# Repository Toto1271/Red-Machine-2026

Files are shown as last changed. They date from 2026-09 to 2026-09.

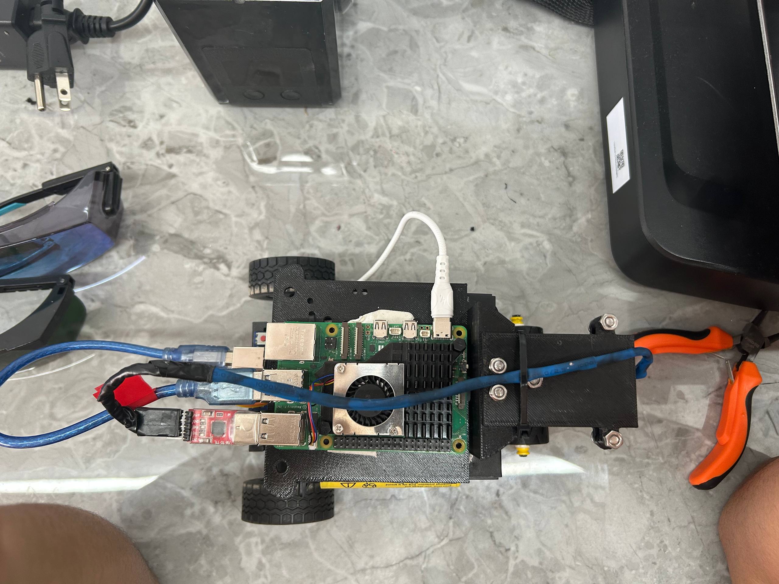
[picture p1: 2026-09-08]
v-photos/photo_4920741823874010308_w.jpg

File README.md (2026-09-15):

# Documento de Ingeniería / Red Machine

Este repositorio muestra todos los componentes para construir a "pompo", este robot autonomo pertenece al equipo "Red Machine" y cumple el proposito de participar en la categoria de futuros ingenieros en la WRO 2026.



# INDICE - REDMACHINE 2026

En este repositorio se puede observar la evolucion del equipo Red Machine asi como su trabajo durante mas de 3 años en la WRO. A través de diversos commits se pueden visualizar los avances que se han tenido durante esta temporada 2026 en procesos de ingeniería, tanto físicos como de computacion y programacion. 
Aquí se podrá observar las decisiones que se han tomado y el por que, y todas las mejoras que se han tomado para llegar a la ultima version hasta el momento que se tiene del robot. 

## 📌 CONTENIDO PRINCIPAL

1. [Documento de Ingeniería / Red Machine](#documento-de-ingeniería--red-machine)
2. [Introducción](#introduccion)
3. [Miembros de Red Machine](#miembros-de-red-machine)
   - [Juan Diego Cano Barros](#-juan-diego-cano-barros)
   - [Samuel José Galban Franco](#-samuel-josé-galban-franco)
   - [Angel Saúl Rodríguez Guerra](#-angel-saúl-rodriguez-guerra)
4. [Fotos del Robot (Todos los Ángulos)](#fotos-desde-todos-los-angulos)
5. [Diseño y Fabricación Mecánica](#-diseño-y-fabricación-mecánica)
   - [Fabricación Digital y Selección de Materiales](#1-fabricación-digital-y-selección-de-materiales)
   - [Análisis del Chasis Inferior (Placa Base)](#2-análisis-detallado-del-chasis-inferior-placa-base)
   - [Análisis del Segundo Piso y Unión entre Niveles](#3-análisis-detallado-del-segundo-piso-y-unión-entre-niveles)
   - [Módulo de Ruedas y Selección de Neumáticos](#4-módulo-de-ruedas-y-selección-de-neumáticos)
   - [Evolución del Chasis y Prototipado CAD](#5-evolución-del-chasis-y-prototipado-cad)
   - [Módulo de Tracción y Centro de Masa](#6-módulo-de-tracción-y-centro-de-masa)
   - [Módulo de Dirección y Comportamiento Dinámico](#7-módulo-de-dirección-y-comportamiento-dinámico)
   - [Integración de Sensores y Estructura Superior](#8-integración-de-sensores-y-estructura-superior)
6. [Explicación Detallada de los Componentes Electrónicos](#explicación-detallada-de-los-componentes)
   - [Raspberry Pi 5](#raspberry-pi-5)
   - [Arduino Uno](#arduino-uno)
   - [Lidar LDROBOT ST27L](#lidar-ldrobot-st27l)
   - [Servomotor REV Robotics](#servomotor-rev-robotics)
   - [Driver TB6612FNG (Puente H Dual)](#driver-tb6612fng-puente-h-dual)
   - [Cámara Webcam](#cámara-webcam)
   - [Banco de Baterías 18650 (2S2P)](#banco-de-baterías-18650-arreglo-2s2p)
   - [Reductor de Voltaje XL4015](#reductor-de-voltaje-xl4015-step-down-5-a)
   - [Reductor de Voltaje LM2596](#reductor-de-voltaje-lm2596-step-down-3-a)
7. [Alimentación del Robot](#alimentación-del-robot)
   - [Cálculo del Consumo Total de Energía](#-cálculo-del-consumo-total-de-energía)
   - [Distribución de Potencia y Autonomía Estimada](#-distribución-de-potencia-y-autonomía-estimada)
8. [Buenas Prácticas de Cableado, Eficiencia y Seguridad](#buenas-prácticas-de-cableado-eficiencia-y-seguridad)
9. [Arquitectura Funcional y Distribución Eléctrica](#arquitectura-funcional-y-distribución-eléctrica)
   - [Capa de Distribución Energética (Power Layer)](#1-capa-de-distribución-energética-power-layer)
   - [Nivel de Procesamiento Jerárquico (Compute Layer)](#2-nivel-de-procesamiento-jerárquico-compute-layer)
   - [Etapa de Tracción y Movilidad (Motor Control Layer)](#3-etapa-de-tracción-y-movilidad-motor-control-layer)
   - [Subsistema de Percepción del Entorno (Sensor Layer)](#4-subsistema-de-percepción-del-entorno-sensor-layer)
   - [Diagrama de Flujo Eléctrico (Mermaid)](#a-continuacion-un-diagrama-que-demuestra-de-manera-mas-sencilla-la-forma-en-la-que-se-alimenta-el-robot)
10. [Preparación de la Raspberry Pi (Software)](#preparación-de-la-raspberry-pi)
    - [Descarga e instalación de Ubuntu Server](#descarga-e-instalación-de-ubuntu-server-en-la-microsd)
    - [Primer arranque y configuración inicial](#primer-arranque-y-configuración-inicial)
    - [Configuración de la red (Wi-Fi e IP fija)](#configuración-de-la-red-wi-fi-e-ip-fija)
11. [Instalación de ROS 2 Jazzy](#instalación-de-ros-2-jazzy-en-la-raspberry-pi)
    - [Configuración del locale](#configuración-del-locale)
    - [Adición del repositorio de ROS 2](#adición-del-repositorio-de-ros-2)
    - [Instalación de ROS 2 Jazzy](#instalación-de-ros-2-jazzy-en-la-raspberry-pi-1)
    - [Configuración del entorno](#configuración-del-entorno)
12. [Configuración del entorno de desarrollo (VS Code Remote)](#configuración-del-entorno-de-desarrollo-en-tu-ordenador-local)
    - [Instalación de Visual Studio Code](#instalación-de-visual-studio-code)
    - [Instalación de la extensión Remote-SSH](#instalación-de-la-extensión-remotessh)
    - [Conexión remota a la Raspberry Pi](#conexión-remota-a-la-raspberry-pi-desde-vs-code)
13. [Preparación del código en la Raspberry Pi](#preparación-del-código-en-la-raspberry-pi)
    - [Creación del workspace de ROS 2](#creación-del-workspace-de-ros-2)
    - [Creación del paquete y del nodo](#creación-del-paquete-y-del-nodo)
    - [Instalación de dependencias Python](#instalación-de-dependencias-python)
14. [Configuración del Arduino Uno](#configuración-del-arduino-uno)
    - [Instalación del Arduino IDE](#instalación-del-arduino-ide-en-ubuntu)
    - [Configuración de permisos del puerto serial](#configuración-de-permisos-del-puerto-serial)
    - [Conexión física del Arduino Uno](#conexión-física-del-arduino-uno-a-la-raspberry-pi)
    - [Compilación y carga del código](#compilación-y-carga-del-código-en-el-arduino)
15. [Comunicación Serial entre ROS 2 y Arduino](#comunicación-serial-entre-ros-2-y-arduino)
    - [Identificación del puerto serial](#identificación-del-puerto-serial)
    - [Permisos del puerto serial](#permisos-del-puerto-serial)
    - [Creación de una regla udev permanente](#creación-de-una-regla-udev-permanente)
16. [Compilación y ejecución del proyecto](#compilación-y-ejecución-del-proyecto)
    - [Compilación del workspace](#compilación-del-workspace)
    - [Configuración de variables de entorno](#configuración-de-variables-de-entorno)
    - [Ejecución del nodo](#ejecución-del-nodo)
17. [Explicación Detallada del Código del Reto Abierto](#explicación-detallada-del-código-del-reto-abierto-y-su-lógica)
    - [Lógica de Navegación Global](#lógica-de-navegación-global)
    - [Nodo ROS 2 (Configuración Inicial, Callback, Filtrado)](#explicacion-codigo-reto-abierto-nodo-ros-2)
    - [Algoritmo de Seguimiento de Pared con SVD](#algoritmo-de-seguimiento-de-pared-con-svd-singular-value-decomposition)
    - [Comunicación con el Arduino](#comunicación-con-el-arduino)
18. [Análisis del Código Arduino (Controlador de Bajo Nivel)](#análisis-del-código-arduino-controlador-de-bajo-nivel)
    - [Control del Motor con PWM](#1-control-del-motor-con-pwm)
    - [Manejo de Comandos Seriales](#2-manejo-de-comandos-seriales)
19. [Solución de problemas comunes](#solución-de-problemas-comunes)
20. [Recomendaciones finales](#recomendaciones-finales)
21. [Videos del Robot](#videos)
    - [Video Actual Reto 1](#video-actual-reto-1)
    - [Video Actual Reto 2](#video-actual-reto-2)
    - [Videos del robot versión 1.0](#videos-del-robot-versión-10)
    - [Videos del robot versión 2.0](#videos-del-robot-versión-20)
    - [Demostraciones y pruebas](#videos-del-robot)
    - [Videos sobre Red Machine](#videos-sobre-red-machine)
22. [Historia y Cronología de Red Machine](#historia-y-cronología-de-red-machine)
    - [Temporada 2023](#temporada-2023)
    - [Temporada 2024](#temporada-2024)
    - [Temporada 2025](#temporada-2025)
23. [Evolución de los Robots (Julián, Luka y Pompo)](#julian-luka-and-pompo)
    - [JULIAN 1.0 a 5.0](#julian-10)
    - [LUKA 1.0 a 3.0](#luka-10)
    - [POMPO 1.0 a 3.0](#pompo-10)
24. [Decisiones de Ingeniería](#decisiones-de-ingeniería)
    - [Filosofía de Diseño y Estrategia](#1-filosofía-de-diseño-y-estrategia)
    - [Sistema de Alimentación y Tracción](#2-sistema-de-alimentación-y-tracción)
    - [Sistemas de Navegación y Sensores](#3-sistemas-de-navegación-y-sensores)
    - [Integración y Control](#4-integración-y-control)

# Contenido

Este repositorio contiene los siguientes directorios para organizar nuestro proyecto:

* `t-photos`: Incluye fotos del equipo, así como fotos del trabajo realizado durante todos los años de competencia y fotos de los robots construidos por el equipo.
* `v-photos`: Contiene 6 fotos del vehículo (desde todos los ángulos).
* `schemes`: Diagramas esquemáticos (JPEG, PNG o PDF) de los componentes electromecánicos, que ilustran el cableado de los elementos electrónicos y motores, además de una explicación de la función de cada uno.
* `src`: Código del software de control para todos los componentes programados para la competencia.
* `models`: Archivos para el diseño 3D del vehículo.
* `other`: Archivos adicionales para entender cómo preparar el vehículo para la competencia.
     
# Introduccion
El equipo ha puesto su mayor esfuerzo en construir el mejor robot posible. Nuestra preparación para estas olimpiadas se ha basado en un amplio aprendizaje en construcción, diseño y programación, y la experiencia de competencias anteriores ha sido fundamental. Largas horas de análisis de pistas y estudio han llevado a la creación de nuestra propia estrategia, basada en los componentes con los que el equipo decidió trabajar, apuntando al mejor rendimiento posible en las distintas etapas de esta competencia.
A lo largo de este documento y de todo el repositorio, se explica con precisión todo el trabajo de diseño, programación y construcción del robot.

# Miembros de Red Machine

## 👤 Juan Diego Cano Barros

### Rol en el equipo
Responsable de la programación del robot y de la electrónica del mismo.

### 🧠 Logros académicos

- 🥉 **Medalla de Bronce – Olimpiada Iberoamericana de Matemáticas (2023)**
Representó a Venezuela en la 29ª edición de esta competencia internacional organizada por la OMA en Argentina, tras ser seleccionado entre los 10 mejores del segundo nivel nacional por @acmvenojm.

- 🥈 **Subcampeón – Argentine Mathematics Olympiad Ñandú (2019)**
Participó en el examen oral en Buenos Aires, destacándose como subcampeón en el Nivel 1.

---

### Antecedentes en robótica

- 🇻🇪 **Tricampeón Nacional – Categoría Futuros Ingenieros (WRO Venezuela)**
Ganador de la Olimpiada Nacional de Robótica en tres ediciones consecutivas, representando al estado Zulia y clasificando a las finales internacionales.

- 🌍 **Finalista Internacional – WRO Panamá 2023**
Representó a Venezuela en la Olimpiada Mundial de Robótica, ubicándose en el puesto 25 de 40 equipos en la categoría Futuros Ingenieros.

- 🇹🇷 **Participación Internacional – WRO Turquía 2024**
Formó parte de la delegación venezolana que compitió en la edición mundial celebrada en Turquía, consolidando experiencia en eventos globales de alto nivel.

---

### 💡 Motivación y Enfoque
Comer, dormir, conocer gente, disfrutar de los viajes y dormir

## 👤 Samuel José Galban Franco

### Rol en el equipo
Responsable del repositorio del robot.

### 🧠 Logros académicos

- 🥈 **Subcampeón – Olimpiada Nacional de Química (2024)**
Representó al Liceo Los Robles dicha edición de esta competencia organizada por AVOQUIM.

- 🥈 **Subcampeón – DESAFÍO VIRTUAL MISSIONS PANAMÁ 2023**
Segundo lugar en esta competencia internacional, representando a Venezuela durante la final internacional de la WRO 2023 celebrada en Panamá.

- 🥈 **Medalla de plata – Olimpiada internacional de nanotecnología INOHS**
Participación destacada en la final internacional, formando parte de la delegación Venezolana el año 2025. 

---

### 🤖 Antecedentes en robótica

- 🇻🇪 **Tricampeón Nacional – Categoría Futuros Ingenieros (WRO Venezuela)**
Ganador de la Olimpiada Nacional de Robótica en tres ediciones consecutivas, representando al estado Zulia y clasificando a las finales internacionales.

- 🌍 **Finalista Internacional – WRO Panamá 2023**
Representó a Venezuela en la Olimpiada Mundial de Robótica, ubicándose en el puesto 25 de 40 equipos en la categoría Futuros Ingenieros.

- 🇹🇷 **Participación Internacional – WRO Turquía 2024**
Formó parte de la delegación venezolana que compitió en la edición mundial celebrada en Turquía, consolidando experiencia en eventos globales de alto nivel.

---

### 💡 Motivación y Enfoque
Conocer gente, disfrutar de los viajes y buscar oportunidades de estudio

## 👤 Angel Saúl Rodriguez Guerra

### Rol en el equipo
Responsable de la mecánica del robot

### 🧠 Logros académicos
- 🥇 **Clasificado para el Mundial – Olimpiada Mundial Juvenil de Matemáticas (WYMO) (2024)**
Representó a Venezuela en la Olimpiada Mundial Juvenil de Matemáticas, una competencia internacional que reúne a jóvenes talentos de las matemáticas de todo el mundo para enfrentarse a problemas de alto nivel de exigencia.

- 🔬 **Participante destacado – Olimpiadas de Química y Matemáticas en Venezuela**
Competido en varias ediciones de las Olimpiadas venezolanas, demostrando excelencia y pasión por las ciencias exactas desde una edad temprana.

--- 

### 🤖 Antecedentes en robótica

- 🇻🇪 **Tricampeón Nacional – Categoría Futuros Ingenieros (WRO Venezuela)**
Ganador de la Olimpiada Nacional de Robótica en tres ediciones consecutivas, representando al estado Zulia y clasificando a las finales internacionales.

- 🌍 **Finalista Internacional – WRO Panamá 2023**
Representó a Venezuela en la Olimpiada Mundial de Robótica, ubicándose en el puesto 25 de 40 equipos en la categoría Futuros Ingenieros.

- 🇹🇷 **Participación Internacional – WRO Turquía 2024**
Formó parte de la delegación venezolana que compitió en la edición mundial celebrada en Turquía, consolidando experiencia en eventos globales de alto nivel.

--- 

### 💡 Motivación y Enfoque
Apasionado por el aprendizaje continuo, la resolución creativa de problemas y la colaboración en equipos multidisciplinarios. Su trayectoria en competencias académicas y tecnológicas refleja una motivación genuina para generar un impacto a través del conocimiento y seguir explorando nuevas fronteras del pensamiento científico y la innovación.

---



# Fotos desde todos los angulos

## Montaje actual (WRO nacional) 
La construcción del robot se mantuvo en su mayor parte, manteniendo la posicion de los sistema de manteniniento, sensores y alimentacion, pudiendose observar dos cambios para el vehículo que competirá en la final nacional: 
   - **Cambio estructural:** En el robot se añade una nueva parte impresa en material 3D, que cumple la funcion de tener un mejor recubrimiento en la electronica. 
   - **Fijacion del boton de inicio:** En la nueva estructura impresa se colocó un pequeño espacio para poder fijar el botón de inicio, y mantenerlo estable a la hora de las practicas para impedir daños en dicho sistema. 

|  |  |  |
| :----: | :---: | :---: |
|  |  |  |

# ⚙️ Diseño y Fabricación Mecánica

## 1. Fabricación Digital y Selección de Materiales

* **Diseño CAD e Impresión 3D:** El vehículo fue modelado en software CAD (Autodesk Fusion 360 para volumetría 3D y AutoCAD para perfiles dimensionales de precisión). Toda la fabricación física se realizó en una impresora Creality K1 Max, lo que permitió iterar el chasis con soltura y ajustar tolerancias sobre la marcha.
* **Elección del PETG frente a otros materiales:**
  * **PLA:** Excesivamente rígido y frágil; propenso a fracturas ante impactos o vibraciones.
  * **ABS / ASA:** Propenso a contracción al enfriarse (*warping*), deformando piezas planas del chasis.
  * **Nylon (PA):** Alta higroscopía y mayor complejidad de procesamiento sin ventajas críticas inmediatas.
  * **PETG (Seleccionado):** Equilibrio perfecto entre tenacidad a impactos, flexibilidad justa, estabilidad dimensional y facilidad de procesamiento.
* **Parámetros de Impresión Predeterminados (Creality Print):**
  * **Temperatura de Boquilla:** 240 °C - 245 °C
  * **Temperatura de la Cama:** 70 °C - 80 °C
  * **Velocidad de Impresión:** 50 mm/s - 100 mm/s
  * **Relleno (Infill) y Patrón:** 15% - 20% (Grid / Gyroid)
  * **Enfriamiento de Capa:** 30% - 50%

---

## 2. Análisis Detallado del Chasis Inferior (Placa Base)

)

* **Módulo Frontal de Dirección (Cuello y Alojamiento Servo):**
  * **Hueco Rectangular Central:** Diseñado a medida para embutir el servomotor de dirección a presión, evitando desplazamientos horizontales al aplicar torque.
  * **Orificios Pasantes M5:** Patrón de cuatro perforaciones perimetrales calibradas para tornillos M5 que fijan el subchasis superior de la dirección.
* **Módulo Trasero de Tracción (Caja, Motores y Salida de Ruedas):**
  * **Cavidades Longitudinales Dobles:** Espacios calados a medida para albergar dos motores eléctricos DC y definir la trocha trasera.
  * **Pieza de Acoplamiento Inter-Motor:** Canal central con puente rígido impreso que conecta ambos motores entre sí, eliminando torsiones independientes al acelerar.
  * **Aberturas Laterales Posteriores:** Muescas/huecos calados en los bordes laterales del chasis cerca del extremo trasero, diseñados específicamente para permitir el paso y salida de los ejes y neumáticos de tracción sin roces con la estructura.
* **Puntos de Fijación Posteriores:**
  * **Pestañas Traseras Perforadas:** Dos extensiones finales que sirven como puntos de anclaje traseros para la estructura del nivel superior.

---

## 3. Análisis Detallado del Segundo Piso y Unión entre Niveles

)

* **Unión Física entre el Primer y Segundo Piso:**
  * **Portabaterías como Columnas de Apoyo:** Los portabaterías dobles para celdas Li-Ion 18650 están colocados en los laterales entre ambas placas, funcionando como las paredes/columnas de soporte principales que elevan la estructura y bajan el centro de gravedad.
  * **Fijación Frontal con Dos Tornillos:** Dos tornillos pasantes atornillan la parte delantera del segundo piso al chasis inferior para eliminar vibraciones en la zona del sensor.
* **Componentes en la Cara Superior del Segundo Piso:**
  * **Raspberry Pi 5:** Montada en la zona central sobre cuatro orificios M3 con *standoffs* mecánicos para ventilación y aislamiento de vibraciones.
  * **Sensor LiDAR:** Instalado en la pestaña frontal elevada (~10 cm del suelo) para escanear la pista por encima de las paredes sin obstáculos ni puntos ciegos.
* **Componentes en la Cara Inferior del Segundo Piso (Montaje de Cabeza):**
  * **Ubicación Invertida:** El driver de potencia (Puente H) y los dos reductores de voltaje (Buck Converters) van suspendidos boca abajo en la cara inferior, orientados hacia el primer piso para ahorrar espacio superior.
  * **Sujeción por Remaches y Alambres:** Fijados combinando remaches rígidos contra vibraciones y alambres de amarre técnico que funcionan como abrazaderas sin ocupar volumen adicional con tuercas o tornillos.
  * **Alimentación Separada:** Reductores independientes para aislar la línea del procesador de la línea de potencia de los motores.

---

## 4. Módulo de Ruedas y Selección de Neumáticos

)

La selección de neumáticos se abordó separando técnicamente las funciones de **tracción** y **dirección**, ya que cada una exige propiedades físicas distintas: la tracción necesita maximizar agarre y transferencia de torque, mientras que la dirección necesita minimizar resistencia e inercia al giro. Por eso se optó por un principio de selección combinada, usando dos tipos de rueda Lego Technic distintos según la función de cada eje, en lugar de un único modelo para las cuatro ruedas.

### Tren Trasero (Tracción)

Se utilizaron ruedas Lego Technic medianas de banda ancha (49.5 x 20 mm). Su banda de rodadura ancha y su compuesto de goma suave maximizan la superficie de contacto con la pista, lo que evita el patinaje al acelerar a fondo con los motores DC y asegura una transferencia de torque eficiente. El diámetro se eligió específicamente para equilibrar torque y velocidad lineal, evitando sobrecargar la etapa de potencia del sistema.

Esta elección también resultó relevante para la estabilidad general del robot: durante las primeras pruebas de rodaje se detectaron derrapes frecuentes, corregidos finalmente invirtiendo la orientación de los motores traseros (ver Sección 5.1). Una banda de rodadura de menor agarre en este punto habría dificultado aún más esa corrección.

### Tren Delantero (Dirección)

Para el eje delantero se emplearon ruedas Lego Technic pequeñas de bajo perfil, montadas sobre manguetas articuladas Lego Technic. Su diámetro reducido y huella angosta minimizan el momento de inercia y la resistencia a la rotación lateral, permitiendo virajes inmediatos sin forzar ni sobrecalentar el servomotor de dirección.

Además, se definió una trocha delantera más estrecha que la trasera, buscando específicamente evitar el sobreviraje (*drifting*) y lograr curvas más fluidas y predecibles. El perfil bajo de esta rueda también fue una decisión deliberada de espacio: evita interferencias mecánicas con el sensor LiDAR, montado justo por encima de este eje.

---

## 5. Evolución del Chasis y Prototipado CAD

El desarrollo del chasis no partió de un diseño final, sino de un proceso iterativo de prueba y corrección: cada versión se construyó para resolver un problema concreto detectado en la anterior. A continuación se documenta esa evolución.

### 5.1. Piso Inferior (Chasis Base)

**Prototipo 1 — Silueta monocapa (boceto de referencia)**

El primer prototipo fue una placa plana simple, sin ningún detalle funcional. Su objetivo no era ser una pieza definitiva, sino tener por primera vez una base física del robot que permitiera observar el avance real de la estructura y, sobre todo, medir con precisión dónde debían ubicarse los sensores, las tarjetas electrónicas y los motores dentro del chasis. Como era de esperarse, esta primera versión no era funcional: le faltaban todos los detalles específicos (cajas, huecos, anclajes) necesarios para encajar los componentes del robot.

)

**Prototipo 2 — Caja inferior integrada**

A partir de las medidas obtenidas en el Prototipo 1, se integró una caja diseñada a medida donde los motores encajan por presión, evitando así depender de tornillos u otro método de fijación adicional para sujetarlos. Este acople resultó tan preciso que se mantiene sin cambios hasta el diseño final. De igual forma, el hueco para el servomotor de dirección quedó correctamente dimensionado desde esta iteración y tampoco requirió modificaciones posteriores.

)

**Prototipo 3 — Nivelación de tracción y liberación de espacio para el LiDAR**

Con la caja de motores ya resuelta, surgió un nuevo problema: las ruedas de tracción trasera y las ruedas de dirección delantera no quedaban al mismo nivel. Para corregirlo, se profundizó la caja inferior hasta emparejar ambos ejes. Además, se eliminó el soporte delantero que existía hasta ese momento, ya que el LiDAR necesitaba ese mismo espacio libre para operar correctamente: mantenerlo habría bloqueado parte de su campo de visión.

)

**Iteración final del piso 1 — Corrección de estabilidad**

Durante las primeras pruebas de rodaje, el robot presentaba derrapes frecuentes por falta de estabilidad. La causa se rastreó hasta la orientación de los motores traseros, por lo que se invirtieron. Este cambio obligó también a repensar cómo se apoyaba el segundo piso sobre el primero, lo que llevó a una decisión clave del diseño: usar los propios portabaterías laterales como columnas estructurales de soporte entre ambos niveles, en lugar de agregar piezas adicionales solo para ese fin.

### 5.2. Segundo Piso y Torre del LiDAR

**Primer prototipo del segundo piso**

Esta primera versión incorporó la base de montaje de la Raspberry Pi y una elevación para sujetar el LiDAR desde arriba, condición necesaria para darle el campo de visión requerido. Ya incluía los agujeros de fijación del LiDAR, aunque el resto de la pieza aún era provisional.

)

**Segundo prototipo del segundo piso — Anclaje delantero**

Al eliminar en el Prototipo 3 del piso inferior el soporte delantero (por interferir con el LiDAR), se perdió también el punto que sostenía la parte frontal del robot. Se resolvió con un tornillo largo de aproximadamente 12 cm que atraviesa todo el vehículo: sujeta el servomotor, separa ambos pisos a la distancia correcta y llega hasta la parte superior del segundo piso, funcionando como eje de unión vertical.

)

**Restricción de altura del LiDAR**

Un condicionante que atravesó todo el rediseño del segundo piso fue que el campo de visión del LiDAR debe mantenerse por debajo de los 10 cm de altura. Los primeros puntos de apoyo ubicados en esa zona no tenían la resistencia estructural necesaria para sostener nada, así que tuvieron que descartarse. La solución definitiva combinó el tornillo largo pasante con los portabaterías laterales actuando como columnas, logrando una sujeción firme sin invadir el espacio que el LiDAR necesita para escanear la pista.

**Diseño final del segundo piso**

La versión definitiva se hizo más ancha para que los portabaterías apoyaran directamente contra el segundo piso (reforzando el punto anterior), e incorporó los huecos exactos para montar la Raspberry Pi de forma visible en la cara superior, y el puente H junto con los reguladores de voltaje boca abajo en la cara inferior, aprovechando así el espacio disponible.

)

### 5.3. Validación con el Prototipo Ensamblado

Antes de dar por cerrado el diseño, se realizó un primer ensamblaje físico completo (dos pisos, ruedas, motores y estructura de sujeción del sensor) para validar que el conjunto funcionara como se había planeado en CAD. Esta prueba confirmó que el enfoque general era el correcto, y fue precisamente al intentar montar los sensores sobre esta estructura que se detectaron las limitaciones de altura del LiDAR descritas en la sección anterior, lo que disparó los ajustes finales del segundo piso y del sistema de anclaje.

)

### 5.4. Prototipo Final Ensamblado (Red Machine)

Como resultado de todo este proceso iterativo —resolver primero la caja de motores, luego nivelar la tracción, después liberar espacio para el LiDAR, y finalmente resolver el anclaje delantero y la estabilidad del segundo piso— se llegó al ensamble físico final: una estructura de dos niveles con dirección híbrida PETG-Lego, soporte de LiDAR elevado por debajo del límite de 10 cm, portabaterías 18650 laterales que cumplen doble función (energía y soporte estructural), y Raspberry Pi 5 montada en la cara superior del segundo piso junto a su disipador de calor.

)

---

## 6. Módulo de Tracción y Centro de Masa

La tracción del robot es trasera, con transmisión directa de potencia desde los dos motores DC montados en la caja inferior del chasis (ver Sección 5.1). Esta configuración simplifica la cadena mecánica al eliminar la necesidad de un diferencial o transmisión hacia el eje delantero, que queda dedicado exclusivamente a la dirección.

Para mantener un centro de gravedad bajo (CoG), los componentes más pesados —las baterías 18650, la Raspberry Pi 5, el Arduino y el cableado principal— se ubicaron en la zona baja e intermedia del chasis. Esta decisión no solo mejora la estabilidad en curva y reduce el riesgo de vuelco, sino que también aprovecha una solución estructural ya usada en el diseño: los propios portabaterías laterales funcionan como columnas de soporte entre los dos pisos (ver Sección 5.1), por lo que el peso queda distribuido en el mismo punto que sostiene físicamente la estructura superior.

---

## 7. Módulo de Dirección y Comportamiento Dinámico

El comportamiento dinámico del robot en curva se controló principalmente a través de la geometría del eje delantero. Al reducir la trocha delantera respecto a la trasera, se acorta el brazo de palanca al girar, lo que se traduce en una respuesta de dirección más ágil e inmediata (ver también Sección 4, Tren Delantero).

Esta misma reducción de trocha, junto con la selección de neumáticos delanteros de bajo perfil y menor momento de inercia, ayuda a controlar el agarre en curva y evitar tanto el sobreviraje (*drifting*) como las mordidas bruscas del tren delantero al iniciar un giro.

A nivel mecánico, el acoplamiento entre el servomotor y las ruedas se resuelve mediante manguetas Lego Technic articuladas, accionadas directamente por el servo. Este acoplamiento híbrido PETG-Lego elimina holguras en la transmisión del movimiento y suaviza la respuesta de dirección, evitando el juego mecánico que introduciría un sistema de varillas o engranajes impresos adicionales.

---

## 8. Integración de Sensores y Estructura Superior

La posición del sensor LiDAR fue uno de los factores que más influyó en el diseño del segundo piso (ver Sección 5.2). Se ubicó a una altura de aproximadamente 10 cm sobre el nivel de las paredes de la pista, lo suficiente para lograr un escaneo despejado de ~270° sin que la propia estructura del robot bloquee su campo de visión.

Esta posición elevada exige, a su vez, una fijación especialmente rígida: cualquier flexión o vibración en la torre del LiDAR se traduce directamente en error de lectura. Por eso la sujeción combina tornillos pasantes con las paredes laterales de las baterías, que —como se describió en la Sección 6— ya cumplen función estructural como columnas de soporte. Esta doble función evita agregar piezas exclusivamente dedicadas a rigidizar la torre del sensor.

Finalmente, el cableado entre ambos pisos se organiza a través de canales dedicados en el chasis, protegiendo las conexiones eléctricas de posibles roces, tirones o cortes durante el movimiento del robot, y manteniendo un espacio de trabajo ordenado para mantenimiento y depuración.

---
# Explicación Detallada de los Componentes

### Raspberry Pi 5
Computadora monoplaca de alto rendimiento equipada con un procesador Broadcom BCM2711 Quad-Core ARM Cortex-A72 a 1.5 GHz. Funciona como la unidad central de cómputo del robot, asumiendo el procesamiento pesado de imágenes capturadas por la webcam y la gestión de la nube de puntos transmitida por el Lidar ST27L. Su arquitectura ARM de 64 bits y su memoria RAM permiten ejecutar la pila del sistema operativo Linux (UBUNTU) e hilos paralelos mediante Python, garantizando que el procesamiento visual intensivo y la construcción del mapa espacial no generen cuellos de botella ni bloqueen las respuestas dinámicas del vehículo en la pista. Fue especificamente utilizada por encima de la raspberry pi 4, ya que completa cada iteracion del codigo un 13% mas rapido, ofreciendo aun mas precision, siendo muy relevante para el uso del lidar.



---

### Arduino Uno
Microcontrolador de 8 bits basado en el chip ATmega328P que opera a una frecuencia de reloj de 16 MHz. Dentro de la arquitectura del robot, se desempeña como el nodo de control en tiempo real dedicado a la ejecución de tareas críticas de bajo nivel. Recibe las directivas de movimiento enviadas desde la Raspberry Pi y genera las señales PWM hacia el driver de motores TB6612FNG y al servomotor. Al delegar la temporización estricta de las salidas lógicas a este microcontrolador, se evita que las interrupciones del sistema operativo de la Raspberry Pi causen fluctuaciones en la velocidad de las ruedas o imperfecciones en la respuesta de los actuadores. El arduino uno fue utilizado principalmente para facilitar la construccion de este chasis, debido a que otro tipo de microcontroladores son mucho mas dificiles de encontrar por lo tanto dificultarian poder replicar el chasis.



---

### Lidar LDROBOT ST27L
Sensor óptico de medición de distancia omnidireccional basado en la tecnología dToF (Direct Time-of-Flight), capaz de realizar escaneos de 360° en el plano horizontal a rangos de hasta 25 metros. Emite pulsos de luz láser infrarroja y mide el tiempo exacto que tardan en rebotar contra los obstáculos, generando una matriz de coordenadas espaciales en tiempo real. Esta información es fundamental para los algoritmos de navegación y evasión de paredes, ofreciendo una inmunidad total ante cambios bruscos de iluminación ambiental, sombras sobre la pista o variaciones en el color de la superficie de los muros. Se utiliza el lidar en contraste a los ultrasonidos para obtener una precision ~99.1%, debido a que trabajamos con mayor cantidad de datos, donde somos capaces de trazar una recta que se asemeja a la de las paredes en un 93,4%, lo cual asegura que la raspberry pi no confunda las paredes de la pista con cualquier otro obstaculo de la pista, tales como los conos o los estacionamientos.



---

### Servomotor REV Robotics
Actuador de dirección de grado robótico con piñonería interna metálica de alta resistencia y motor integrado de corriente continua, optimizado para operar a 6.0 V con un torque de hasta 13.5 kg-cm. Su función principal es posicionar el mecanismo del tren delantero para cambiar la trayectoria del vehículo. Su electrónica digital interna ajusta la posición del eje con alta precisión angular, manteniendo el ángulo de dirección fijo sin ceder ante las fuerzas de fricción de las ruedas sobre la pista o las inercias generadas durante cambios de dirección a alta velocidad.



---

### Driver TB6612FNG (Puente H Dual)
Módulo controlador de motores basado en una etapa de potencia MOSFET de baja resistencia interna en estado activo (Rds(on)). Permite manejar dos motores DC en paralelo con una corriente continua de hasta 1.2 A por canal (3.2 A pico). Al utilizar transistores MOSFET en lugar de los antiguos transistores bipolares, ofrece una eficiencia energética superior con una disipación de calor mínima, respondiendo de forma lineal a las señales de ciclo de trabajo PWM de hasta 100 kHz enviadas por el Arduino Uno para regular aceleraciones y frenados. Fue un cambio al antiguo puente h l298n, debido a que este nos ofrece mas eficiencia, en un espacio muchisimo menor, permitiendonos hacer todos los cambios fisicos exigidos.



---

### Cámara Webcam
Sensor de captura de imagen HD conectado vía USB a la Raspberry Pi, dedicado a la adquisición de cuadros de video en tiempo real. Proporciona el flujo de datos visuales necesario para que los algoritmos de visión artificial procesen el entorno, detecten patrones cromáticos, identifiquen señales de tráfico y reconozcan elementos clave del circuito. Su integración directa al bus USB 3.0 de la Raspberry Pi permite la transmisión fluida de imágenes sin sobrecargar el bus de comunicación serie del microcontrolador de bajo nivel.

*(Espacio para foto de la Webcam)*

---

### Banco de Baterías 18650 (Arreglo 2S2P)
Fuente de alimentación principal conformada por cuatro celdas cilíndricas recargables de Ion de Litio (Li-ion) formato 18650, configuradas en dos ramas en paralelo de dos celdas en serie cada una. Entrega una tensión nominal de 7.4 V (8.4 V a plena carga) y una capacidad acumulada de 4000 mAh. Esta química de batería ofrece una resistencia interna extremadamente baja, lo que permite suministrar ráfagas elevadas de corriente sin sufrir caídas parásitas de voltaje (*brownouts*) cuando los motores de tracción y el servo de dirección demandan torque máximo en momentos de alta aceleración.



---

### Reductor de Voltaje XL4015 (Step-Down 5 A)
Convertidor conmutado de corriente continua (*Buck Converter*) capaz de transformar el voltaje variable del banco de baterías (7.4 V – 8.4 V) en una línea regulada estable de 5.0 V DC con capacidad de suministro de hasta 5 A. Su frecuencia de conmutación interna y su alto rendimiento energético (hasta el 96%) evitan el desperdicio de energía en forma de calor residual, suministrando una alimentación limpia e inmune a ruidos electromagnéticos a la Raspberry Pi, la cual a su vez energiza la webcam, el Lidar ST27L y el Arduino Uno. Este componente es estrictamente necesario, debido a que la mayoria de reductores de voltaje de bajo costo suministran una cantidad menor a 4A, lo cual es necesario para el correcto funcionamiento de la raspberry pi, y por lo tanto de sus componentes adyacentes



---

### Reductor de Voltaje LM2596 (Step-Down 3 A)
Regulador conmutado independiente que opera a una frecuencia de 150 kHz, dedicado a transformar la tensión de las baterías en una salida fija de 6.0 V DC para la etapa de dirección. Al estar aislado de la línea de 5.0 V de la computadora principal, absorbe los picos térmicos y electromagnéticos que genera el servomotor REV Robotics durante sus movimientos bruscos, previniendo que el ruido inductivo del motor o los bajones de tensión repentinos causen reinicios imprevistos en la Raspberry Pi o fallas de sincronía en el Lidar.



---

# Alimentación del Robot

El sistema de energía del robot está estructurado mediante dos reguladores *step-down* conectados al paquete principal de baterías:

- **Línea de Cómputo y Percepción:** El regulador XL4015 reduce el voltaje de las baterías a 5 V estables para alimentar la Raspberry Pi. Esta, a su vez, distribuye energía al Arduino Uno, al Lidar LDROBOT ST27L y a la webcam a través de sus puertos USB e interfaces de alimentación.
- **Línea de Actuación (Servo):** El regulador LM2596 ajusta la tensión a 6 V para alimentar de forma dedicada el servomotor REV Robotics, aislando sus picos de corriente del resto del circuito lógico.
- **Línea de Tracción:** Las baterías alimentan directamente la entrada de potencia del puente H TB6612FNG, el cual distribuye la energía a ambos motores de tracción conectados en paralelo.

---

### 🔋 Cálculo del Consumo Total de Energía

| Componente | Cantidad | Consumo estimado (mA) | Total (mA) |
|:---|:---:|:---:|:---:|
| Raspberry Pi (con Webcam) | 1 | 1200 mA | 1200 mA |
| Lidar LDROBOT ST27L | 1 | 350 mA | 350 mA |
| Arduino Uno | 1 | 50 mA | 50 mA |
| Servomotor REV Robotics | 1 | 180 mA (típico) | 180 mA |
| Motores de Tracción (en paralelo) | 2 | 500 mA c/u | 1000 mA |
| **TOTAL** | — | — | **2780 mA** |

---

### ⚡ Distribución de Potencia y Autonomía Estimada

El sistema se alimenta de forma distribuida para optimizar la eficiencia y proteger los componentes sensibles contra ruido inductivo:

- 🔌 **Línea Regulada XL4015 (5V):** Raspberry Pi, Webcam, Lidar ST27L y Arduino Uno.
- 🔌 **Línea Regulada LM2596 (6V):** Servomotor REV Robotics.
- 🔋 **Alimentación Directa a Puente H TB6612FNG:** Motores de tracción conectados en paralelo.

| Fuente de Alimentación | Componentes Alimentados | Consumo Estimado (mA) | Capacidad Aprox. |
|:---|:---|:---:|:---:|
| Regulador XL4015 (Salida 5V) | Raspberry Pi, Webcam, Lidar, Arduino | ~1600 mA | 4000 mAh |
| Regulador LM2596 (Salida 6V) | Servomotor REV Robotics | ~180 mA | 4000 mAh |
| Puente H TB6612FNG (Directo) | Motores de Tracción (en paralelo) | ~1000 mA | 4000 mAh |

> 💡 *Nota:*  Al momento de utilizarlos todos en conjunto tienen una autonomia estimada de 1.2 horas de forma eficiente
> 

# Buenas Prácticas de Cableado, Eficiencia y Seguridad

* **Estandarización de colores por función:** Se utilizó el mismo color de cable para cada tipo de línea en todo el robot (rojo para positivo, negro para tierra, azul para señales PWM, amarillo/verde para comunicación). Esto evita confusiones durante las reparaciones y previene conexiones cruzadas accidentales. En competencias pasadas esto no era un estandar, lo que generaba confusiones al momento de la reparacion

* **Separación física de cables de energía y datos:** Se pasaron los cables gruesos que llevan energía a los motores por un lado del chasis y los cables delgados que llevan información a la Raspberry Pi, Lidar y Arduino por el otro. Mantenerlos alejados evita que la fuerza de los motores cause interferencias en las lecturas de los sensores.

* **Trenzado de cables de alimentación:** Los cables de corriente (positivo y negativo) que van hacia los motores y los reguladores se enrollaron juntos en pares trenzados. Esta forma de enroscarlos ayuda a cancelar de forma natural el ruido magnético que generan sobre el resto de la electrónica. De igualmente facilitan solucionar cualquier error, ya que hay mucho menor volumen de cables

* **Uso de tubos termorretráctiles (Thermoshrink) en las soldaduras:** Cada unión soldada se cubrió con tubo termorretráctil en lugar de usar cinta aislante. Esto garantiza que las soldaduras no queden expuestas, evitando cortocircuitos por contacto accidental con el chasis u otros componentes.

* **Agrupado con precintos y fundas espirales:** Se utilizaron precintos plásticos y fundas para juntar los cables en ramas ordenadas. Esto evita que queden cables sueltos que puedan engancharse con las ruedas, el servomotor o con elementos externos de la pista mientras el robot se desplaza.

* **Alivio de tensión en zonas con movimiento:** En los cables que van conectados a partes móviles, como el servomotor de la dirección, se dejó una ligera curvatura de margen y se sujetó el cable al chasis justo antes del conector. Así, el tirón del movimiento lo absorbe la estructura del robot y no los pines del componente.

##  Arquitectura Funcional y Distribución Eléctrica

El diseño eléctrico e informático del vehículo se estructura en cuatro capas principales, ideadas para maximizar el rendimiento computacional, aislar las interferencias electromagnéticas y asegurar tiempos de reacción inmediatos en la pista:

#### 1. Capa de Distribución Energética (Power Layer)
El suministro eléctrico nace de un arreglo de almacenamiento principal (dos paquetes de dos baterías 18650 conectadas en paralelo). A partir de este nodo, la energía se ramifica de manera independiente:

*   **Regulador XL4015 (Núcleo Lógico):** Convierte el voltaje del banco de baterías en una salida constante de 5.0V con un límite de hasta 5A. Esta fuente de alta capacidad está dedicada enteramente a sostener el consumo de la Raspberry Pi 5, permitiéndole alimentar sin problemas a los dispositivos conectados a sus propios puertos.
*   **Regulador LM2596 (Fuerza de Dirección):** Crea una línea de alimentación completamente aislada del resto del sistema, enfocada de manera exclusiva en el servomotor REV Robotics. Esta separación física evita que las caídas de voltaje producidas al girar las ruedas delanteras interfieran con la estabilidad de los procesadores.
*   **Derivación Directa a Tracción:** El voltaje íntegro de las celdas 18650 se conecta de forma directa a la entrada de fuerza del controlador de motores (TB6612FNG), asegurando que los motores tengan acceso instantáneo a la corriente máxima requerida para la aceleración.

#### 2. Nivel de Procesamiento Jerárquico (Compute Layer)
La inteligencia del robot opera mediante un esquema de delegación de tareas para evitar sobrecargas informáticas:

*   **Computadora Central (Raspberry Pi 5):** Funciona como el cerebro de la operación. Aprovechando su gran poder de cálculo, gestiona de forma exclusiva los algoritmos pesados de visión artificial y la construcción del mapa Lidar. Paralelamente, actúa como el concentrador central (Hub) que provee datos y energía USB al resto de la electrónica lógica.
*   **Controlador Cinético (Arduino Uno):** Alimentado y comunicado a través de un puerto USB de la Raspberry Pi 5, este microcontrolador se libera de los cálculos complejos para enfocarse 100% en el manejo de tiempos reales. Transforma las instrucciones recibidas en señales PWM exactas para gobernar el puente H y el servomotor.
*   **Unificación de Masas (Star Grounding):** Para garantizar que los niveles lógicos sean leídos correctamente, todos los retornos negativos (GND) se referencian a un único punto central vinculado a la Raspberry Pi 5, previniendo errores de voltaje en las comunicaciones.

#### 3. Etapa de Tracción y Movilidad (Motor Control Layer)
La ejecución física de los comandos de aceleración recae sobre el puente H TB6612FNG, optimizado para operaciones de alta eficiencia:

*   **Traducción de Comandos:** Recibe las señales digitales (dirección y PWM) enviadas por los pines de salida del Arduino Uno. Gracias a sus transistores internos de baja pérdida, reacciona instantáneamente para aplicar frenados dinámicos o cambios de velocidad.
*   **Empuje Sincronizado:** Las salidas de potencia de este módulo se enlazan a los dos motores de tracción que comparten una conexión en paralelo. Esto fuerza a ambos motores a recibir el mismo diferencial eléctrico, garantizando un empuje equilibrado y lineal en las ruedas.

#### 4. Subsistema de Percepción del Entorno (Sensor Layer)
El monitoreo del circuito se lleva a cabo mediante periféricos de alto flujo de datos conectados de forma nativa a los puertos de la computadora principal:

*   **Escaneo Láser (Lidar LDROBOT ST27L):** Aporta la telemetría espacial escaneando los obstáculos a su alrededor en 360 grados. Obtiene tanto su energía como su canal de comunicación a través de un cable USB conectado directo a la Raspberry Pi 5, inyectando su nube de puntos a alta velocidad.
*   **Visión Computacional (Webcam HD):** Captura las referencias visuales y marcadores de color del circuito. Su interfaz USB envía el flujo de imágenes directamente al procesador de la Raspberry Pi 5 sin pasar por el Arduino, evitando cualquier tipo de retraso o cuello de botella en los buses del microcontrolador de bajo nivel.

A continuacion, un diagrama que demuestra de manera mas sencilla la forma en la que se alimenta el robot

```mermaid
%%{init: {'theme': 'base', 'themeVariables': { 'primaryColor': '#ffffff', 'edgeLabelBackground':'#ffffff', 'tertiaryColor': '#f4f5f7'}}}%%
graph TB
    %% Configuración de Estilos
    classDef batt fill:#FFD1DC,stroke:#D1495B,stroke-width:2px,color:#000,font-weight:bold;
    classDef pwr fill:#FFE5D9,stroke:#F77F00,stroke-width:2px,color:#000,font-weight:bold;
    classDef brain fill:#D8E2DC,stroke:#2A9D8F,stroke-width:2px,color:#000,font-weight:bold;
    classDef usb fill:#E8E8E4,stroke:#4A4E69,stroke-width:2px,color:#000,font-weight:bold;
    classDef motor fill:#FCD5CE,stroke:#E63946,stroke-width:2px,color:#000,font-weight:bold;

    subgraph POWER_LAYER [" ⚡ ETAPA DE POTENCIA Y REGULACIÓN "]
        direction TB
        BAT["🔋 2x Packs 18650 en Paralelo<br/>(Alimentación Principal)"]:::batt
        
        REG_SUB[" "]
        XL["⚡ Step-Down XL4015<br/>(5V / 5A)"]:::pwr
        LM["⚡ Step-Down LM2596<br/>(6V Regulado)"]:::pwr
        TB["🔌 Driver TB6612FNG<br/>(Puente H Dual)"]:::pwr
    end

    subgraph COMPUTE_LAYER [" 🧠 PROCESAMIENTO Y CONTROL "]
        direction TB
        PI["🍓 Raspberry Pi 5<br/>(Cálculo Principal / Visión)"]:::brain
        ARD["🤖 Arduino Uno<br/>(Control Cinético Tiempo Real)"]:::brain
    end

    subgraph PERIPHERALS [" 🎯 ACTUADORES Y SENSORES "]
        SERVO["⚙️ Servomotor REV Robotics<br/>(Dirección)"]:::motor
        MOT["🛞 2x Motores DC<br/>(Tracción Trasera)"]:::motor
        LIDAR["📡 LiDAR ST27L"]:::usb
        CAM["📷 Webcam HD"]:::usb
    end

    %% Mallas de Alimentación
    BAT ==>|Línea Directa V+| XL
    BAT ==>|Línea Directa V+| LM
    BAT ==>|Alimentación VMOT| TB

    LM -->|Línea limpia 6V| SERVO
    XL -->|Línea limpia 5V| PI

    %% Bus USB y Datos
    PI == "🔌 Bus USB" ==> ARD
    PI == "🔌 Bus USB" ==> LIDAR
    PI == "🔌 Bus USB" ==> CAM

    %% Control de Motores
    ARD -->|Señales PWM / GPIO| TB
    ARD -->|Señal Control PWM| SERVO
    TB -->|Salida Potencia Motores| MOT

    %% Estilos de las líneas
    linkStyle 0,1,2,3,4 stroke:#E63946,stroke-width:2px;
    linkStyle 5,6,7 stroke:#2A9D8F,stroke-width:2px;
    linkStyle 8,9,10 stroke:#4A4E69,stroke-width:2px;
```

## Preparación de la Raspberry Pi

### Descarga e instalación de Ubuntu Server en la microSD

En tu ordenador local, descarga e instala **Raspberry Pi Imager** desde [https://www.raspberrypi.com/software/](https://www.raspberrypi.com/software/). En Ubuntu, puedes instalarlo con:

```bash
sudo snap install rpi-imager
```

Inserta la microSD (mínimo 16 GB, clase 10) en tu lector. Abre Raspberry Pi Imager y sigue estos pasos:
- **Choose OS** → Other specific-purpose OS → Ubuntu → **Ubuntu Server 24.04 LTS (64‑bit)**.
- **Choose Storage** → selecciona tu microSD.

Haz clic en el engranaje (⚙️) para la configuración avanzada:
- Marca **Set hostname** y escribe, por ejemplo, `wro-robot`.
- Marca **Enable SSH** y elige **Use password authentication**.
- Establece el usuario y contraseña que usarás, por ejemplo: Usuario: `wro`, Contraseña: `wro2025`.
- Marca **Configure wireless LAN** e introduce el SSID y la contraseña de tu red Wi‑Fi.
- Marca **Set locale settings**: elige `es_ES.UTF-8` y `Europe/Madrid`.

Haz clic en **Write** y espera a que termine la escritura. Una vez escrita, retira la microSD, insértala en la Raspberry Pi y conecta la alimentación USB‑C.

### Primer arranque y configuración inicial

Al encender, Ubuntu Server arrancará y mostrará un prompt de inicio de sesión. Inicia sesión con el usuario y contraseña que configuraste.

Ejecuta los siguientes comandos para actualizar el sistema e instalar herramientas básicas:

```bash
sudo apt update && sudo apt upgrade -y
sudo apt install -y net-tools git vim curl wget htop
```

Configura la zona horaria y sincroniza la hora (importante para ROS 2 y certificados):

```bash
sudo timedatectl set-timezone Europe/Madrid
sudo apt install -y ntp
sudo timedatectl set-ntp true
```

Reinicia para asegurar que todos los cambios se aplican:

```bash
sudo reboot
```

### Configuración de la red (Wi‑Fi e IP fija)

Si configuraste el Wi‑Fi en el Imager, ya deberías tener conexión. Para verificar:

```bash
ip a
ping -c 4 google.es
```

Para asignar una IP fija (recomendado para SSH), editamos el archivo de configuración de Netplan:

```bash
sudo nano /etc/netplan/50-cloud-init.yaml
```

Sustituye el contenido por el siguiente (ajusta la IP, puerta de enlace y SSID/contraseña a tu red):

```yaml
network:
  version: 2
  ethernets:
    eth0:
      dhcp4: true
      optional: true
  wifis:
    wlan0:
      dhcp4: false
      addresses:
        - 192.168.1.100/24
      routes:
        - to: default
          via: 192.168.1.1
      nameservers:
        addresses: [8.8.8.8, 1.1.1.1]
      access-points:
        "nombre_de_tu_wifi":
          password: "tu_contraseña"
```

Guarda con `Ctrl+O`, Enter, y sal con `Ctrl+X`. Aplica la configuración:

```bash
sudo netplan apply
```

Verifica que tienes la IP asignada:

```bash
hostname -I
```

Anota la IP (ej. `192.168.1.100`).

### Habilitación y configuración de SSH

SSH ya debería estar activo si lo marcaste en el Imager. Para asegurarte:

```bash
sudo systemctl enable ssh
sudo systemctl start ssh
```

Desde tu ordenador local, prueba la conexión:

```bash
ssh wro@192.168.1.100
```

Si todo funciona, ya puedes trabajar sin monitor ni teclado.

---

## Instalación de ROS 2 Jazzy en la Raspberry Pi

Seguimos la [guía oficial de ROS 2 Jazzy para Ubuntu 24.04](https://docs.ros.org/en/humble/Installation/Ubuntu-Install-Debians.html).

### Configuración del locale

```bash
sudo apt update && sudo apt install -y locales
sudo locale-gen es_ES es_ES.UTF-8
sudo update-locale LC_ALL=es_ES.UTF-8 LANG=es_ES.UTF-8
export LANG=es_ES.UTF-8
```

Añade la variable al final de `~/.bashrc` para que persista:

```bash
echo "export LANG=es_ES.UTF-8" >> ~/.bashrc
```

### Adición del repositorio de ROS 2

```bash
sudo apt install -y software-properties-common
sudo add-apt-repository universe
sudo apt update && sudo apt install -y curl
sudo curl -sSL https://raw.githubusercontent.com/ros/rosdistro/master/ros.key -o /usr/share/keyrings/ros-archive-keyring.gpg
echo "deb [arch=$(dpkg --print-architecture) signed-by=/usr/share/keyrings/ros-archive-keyring.gpg] http://packages.ros.org/ros2/ubuntu $(. /etc/os-release && echo $UBUNTU_CODENAME) main" | sudo tee /etc/apt/sources.list.d/ros2.list > /dev/null
```

### Instalación de ROS 2 Humble

```bash
sudo apt update
sudo apt upgrade -y
sudo apt install -y ros-Jazzy-desktop
sudo apt install -y python3-colcon-common-extensions python3-rosdep python3-pip
```

### Configuración del entorno

Añade el sourcing de ROS 2 a tu `.bashrc`:

```bash
echo "source /opt/ros/jazzy/setup.bash" >> ~/.bashrc
echo "source /usr/share/colcon_argcomplete/hook/colcon-argcomplete.bash" >> ~/.bashrc
source ~/.bashrc
```

Inicializa `rosdep`:

```bash
sudo rosdep init
rosdep update
```

---

## Configuración del entorno de desarrollo en tu ordenador local

Vamos a usar **Visual Studio Code** con la extensión **Remote‑SSH** para editar y ejecutar código directamente en la Raspberry Pi.

### Instalación de Visual Studio Code

Descarga e instala VS Code desde [https://code.visualstudio.com/](https://code.visualstudio.com/). En Ubuntu:

```bash
sudo snap install --classic code
```

### Instalación de la extensión Remote‑SSH

Abre VS Code, ve a la pestaña de Extensiones (Ctrl+Shift+X) y busca **Remote - SSH**. Instala la extensión de Microsoft.

### Configuración de la clave SSH para la Raspberry Pi (recomendado)

Para no tener que escribir contraseña cada vez, genera un par de claves en tu ordenador local:

```bash
ssh-keygen -t rsa -b 4096 -C "wro-robot"
```

Copia tu clave pública a la Raspberry Pi:

```bash
ssh-copy-id wro@192.168.1.100
```

Prueba que ya no pide contraseña: `ssh wro@192.168.1.100`.

### Conexión remota a la Raspberry Pi desde VS Code

En VS Code, haz clic en el icono de **Remote Explorer**. Elige **"Add New SSH Host..."** y escribe `wro@192.168.1.100`. Una vez añadido, haz clic en el icono de conexión para abrir una sesión remota.

---

## Preparación del código en la Raspberry Pi

### Creación del workspace de ROS 2

```bash
mkdir -p ~/wro_ws/src
cd ~/wro_ws
```

### Creación del paquete y del nodo

```bash
cd ~/wro_ws/src
ros2 pkg create --build-type ament_python wro_reto_abierto
cd wro_reto_abierto
rm -rf wro_reto_abierto/*.py
touch wro_reto_abierto/wro_reto_abierto_node.py
chmod +x wro_reto_abierto/wro_reto_abierto_node.py
```

Edita el `setup.py` para que el punto de entrada apunte a nuestro nodo:

```python
entry_points={
    'console_scripts': [
        'wro_node = wro_reto_abierto.wro_reto_abierto_node:main',
    ],
},
```

### Instalación de dependencias Python

```bash
sudo pip3 install numpy pyserial
```

---

## Configuración del Arduino Uno

### Instalación del Arduino IDE en Ubuntu

```bash
sudo apt install -y arduino arduino-core
```

### Configuración de permisos del puerto serial

```bash
sudo usermod -a -G dialout wro
```

### Conexión física del Arduino Uno a la Raspberry Pi

Conecta el Arduino Uno a la Raspberry Pi mediante un cable USB tipo B.

### Compilación y carga del código en el Arduino

Crea un archivo `sketch.ino`:

```bash
mkdir -p ~/arduino_sketch
nano ~/arduino_sketch/sketch.ino
```

Código completo del Arduino:

```cpp
#include <Servo.h>

const int pinMotor1 = 4;
const int pinMotor2 = 5;
const int pinServo  = 7;

Servo miServo;

void fijarMotor(int velocidad) {
  velocidad = constrain(velocidad, -150, 150);
  if (velocidad > 0) {
    int pwmResta = 150 - velocidad; 
    analogWrite(pinMotor1, 150);
    analogWrite(pinMotor2, pwmResta);
  } else if (velocidad < 0) {
    int pwmResta = 150 - abs(velocidad);
    analogWrite(pinMotor1, pwmResta);
    analogWrite(pinMotor2, 150);
  } else {
    digitalWrite(pinMotor1, LOW);
    digitalWrite(pinMotor2, LOW);
  }
}

void setup() {
  Serial.begin(115200); 
  pinMode(pinMotor1, OUTPUT);
  pinMode(pinMotor2, OUTPUT);
  miServo.attach(pinServo);
  miServo.write(57);
  fijarMotor(0);
}

void loop() {
  if (Serial.available() > 0) {
    String entrada = Serial.readStringUntil('\n');
    entrada.trim();
    if (entrada.length() > 0) {
      char tipoComando = toupper(entrada.charAt(0)); 
      if (tipoComando == 'S') {
        int angulo = entrada.substring(1).toInt();
        angulo = constrain(angulo, 30, 90);
        miServo.write(angulo);
      } else if (tipoComando == 'M') {
        int velocidad = entrada.substring(1).toInt();
        fijarMotor(velocidad);
      } else if (isDigit(tipoComando) || tipoComando == '-') {
        int angulo = entrada.toInt();
        angulo = constrain(angulo, 30, 90);
        miServo.write(angulo);
      }
    }
  }
}
```

**Carga del sketch** con `arduino-cli`:

```bash
curl -fsSL https://raw.githubusercontent.com/arduino/arduino-cli/master/install.sh | sh
sudo mv bin/arduino-cli /usr/local/bin/
arduino-cli compile --fqbn arduino:avr:uno ~/arduino_sketch/
arduino-cli upload -p /dev/ttyACM0 --fqbn arduino:avr:uno ~/arduino_sketch/
```

---

## Comunicación Serial entre ROS 2 y Arduino

### Identificación del puerto serial

```bash
ls /dev/ttyACM*
```

Normalmente aparecerá `/dev/ttyACM0`.

### Permisos del puerto serial

```bash
sudo chmod 666 /dev/ttyACM0
sudo usermod -a -G dialout $USER
```

### Creación de una regla udev permanente

```bash
sudo nano /etc/udev/rules.d/99-arduino.rules
```

Contenido:
```
SUBSYSTEM=="usb", ATTRS{idVendor}=="2341", ATTRS{idProduct}=="0043", MODE="0666"
```

Recarga las reglas:

```bash
sudo udevadm control --reload-rules
sudo udevadm trigger
```

---

## Compilación y ejecución del proyecto

### Compilación del workspace

```bash
cd ~/wro_ws
colcon build --symlink-install
```

### Configuración de variables de entorno

```bash
echo "source ~/wro_ws/install/setup.bash" >> ~/.bashrc
source ~/.bashrc
```

### Creación del archivo del nodo Python

```bash
nano ~/wro_ws/src/wro_reto_abierto/wro_reto_abierto/wro_reto_abierto_node.py
```

### Ejecución del nodo

```bash
ros2 run wro_reto_abierto wro_node
```

---

## Explicación Detallada del Código del Reto Abierto y su Lógica 

He diseñado este sistema con una arquitectura cliente-servidor donde la Raspberry Pi (ROS 2) actúa como el cerebro principal que procesa los datos del LiDAR y toma decisiones de alto nivel, mientras que el Arduino Uno se encarga del control en tiempo real de los actuadores.

### Lógica de Navegación Global

El flujo de navegación que he implementado sigue un ciclo continuo basado en la detección del entorno:



### Explicacion codigo Reto Abierto (Nodo ROS 2)

He estructurado el nodo en varias capas funcionales para mantener el código limpio y modular.

#### 1. Configuración Inicial y Parámetros

En el método `__init__`, he declarado todos los parámetros ajustables que permiten modificar el comportamiento del robot sin recompilar:

```python
self.declare_parameter('sentido', 0)                    # Dirección de giro (0=desconocido)
self.declare_parameter('distancia_objetivo', 0.4)      # Distancia deseada a la pared (metros)
self.declare_parameter('distancia_frontal_obstaculo', 0.35)  # Umbral para detectar pared frontal
self.declare_parameter('velocidad_motor', 20)          # Velocidad constante
self.declare_parameter('limite_angulo_max', 38.0)      # Límite de corrección angular
```
> [!NOTE]
> Esto facilita completamente calibrar cualquier parametro, no es necesario estar conectador por cable ni volver a compilar nada, unicamente mediante ssh se envia el cambio de parametro al nodo de ROS2

He incluido un sistema PID completo para controlar tanto la distancia como el ángulo respecto a la pared. Los parámetros Kp, Ki y Kd permiten ajustar la respuesta del robot a diferentes velocidades y superficies.

#### 2. Callback del LiDAR (Función Principal)

He implementado la lógica principal en `lidar_callback`, que se ejecuta cada vez que llega un nuevo escaneo del LiDAR:

```python
def lidar_callback(self, msg):
    # Calculo del tiempo entre frames para los PID
    current_time = self.get_clock().now()
    dt = (current_time - self.last_time).nanoseconds / 1e9
    self.last_time = current_time
    
    # Lectura y filtrado de distancias
    self.detectardistancias(msg)
    
    # Lógica de decisión según obstáculos
    if self.d < dist_frontal_limite and self.d > 0:
        # Obstáculo frontal detectado
        if self.sentido == 0:
            self.detectarlado_en_pared()
        # Ejecución de giro
    else:
        # Navegación normal
```
> [!NOTE]
> Esta funcion se usa de igual manera en el reto con obstaculos.

#### 3. Filtrado de Datos del LiDAR

He creado `detectardistancias()` para extraer únicamente los puntos relevantes del escaneo:

- **Frente**: Ángulos de 75° a 105° (para detección de obstáculos frontales)
- **Derecha**: Ángulos de 165° a 195° (para seguimiento de pared derecha)
- **Izquierda**: Ángulos de 345° a 15° (para seguimiento de pared izquierda)

Utilizo el valor mínimo de cada sector como distancia representativa, lo que asegura que el robot reaccione al obstáculo más cercano.

> [!NOTE]
> Esta funcion se usa de igual manera en el reto con obstaculos.

#### 4. Determinación del Sentido de Navegación

El método `detectarlado_en_pared()` compara las distancias laterales cuando el robot encuentra su primera pared frontal:

```python
def detectarlado_en_pared(self):
    if self.dd < self.di:
        self.sentido = 2  # Girar a la derecha y seguir pared derecha
    else:
        self.sentido = 1  # Girar a la izquierda y seguir pared izquierda
```

Esta decisión se toma UNA SOLA VEZ en toda la ejecución, permitiendo que el robot mantenga una estrategia consistente durante todo el recorrido.

> [!NOTE]
> Esta funcion se usa de igual manera en el reto con obstaculos.

#### 5. Algoritmo de Seguimiento de Pared con SVD (Singular Value Decomposition)

He implementado un método avanzado de seguimiento de pared utilizando SVD, que es más robusto que simplemente usar la distancia mínima, esto es esencial, ya que en la pista existen objetos, tales como conos o los estacionamientos, que impiden el correcto funcionamiento del pid.

**Proceso matemático implementado en `calcular_pid_svd()`:**

1. **Transformación de coordenadas polares a cartesianas**: Convierto las lecturas de distancia (r) y ángulo (θ) a coordenadas X,Y:
   ```python
   X = r * cos(θ)
   Y = r * sin(θ)
   ```

2. **Cálculo de la línea de la pared**: Utilizo SVD para encontrar la línea que mejor se ajusta a todos los puntos:
   ```python
   X_c = X - mean(X)
   Y_c = Y - mean(Y)
   _, _, Vh = np.linalg.svd(np.vstack([X_c, Y_c]).T)
   dir_x, dir_y = Vh[0]  # Vector dirección de la pared
   norm_x, norm_y = Vh[1]  # Vector normal a la pared
   ```

3. **Cálculo de errores**:
   - **Error de distancia**: Distancia deseada (0.4m) menos distancia real a la pared
   - **Error de ángulo**: Diferencia entre la orientación de la pared y la dirección deseada (paralela al robot)

4. **Control PID**: Calculo dos salidas PID (una para distancia y otra para ángulo) que se combinan para producir la corrección final del servo:
   ```python
   salida_distancia = Kp_d * error_distancia + Kd_d * derivada_dist + Ki_d * integral_dist
   salida_angulo = Kp_a * error_angulo + Kd_a * derivada_ang
   correccion_total = salida_distancia + salida_angulo
   ```

   > [!NOTE]
> Esta funcion se usa de igual manera en el reto con obstaculos.

#### 6. Comunicación con el Arduino

He diseñado el protocolo de comunicación para ser simple y robusto, esto tambien sirve para manejar el robot de manera inalambrica mediante ssh.

```python
def enviar_a_arduino(self, velocidad, angulo_servo):
    self.arduino.write(f"M{velocidad}\n".encode('utf-8'))
    self.arduino.write(f"S{angulo_servo}\n".encode('utf-8'))
```

- **M<velocidad>**: Controla la velocidad del motor (rango -150 a 150)
- **S<ángulo>**: Controla el ángulo del servo (rango 30 a 90 grados)

### Análisis del Código Arduino (Controlador de Bajo Nivel)

El sketch de Arduino actúa como un intérprete de comandos seriales:

#### 1. Control del Motor con PWM

He implementado `fijarMotor()` para controlar un motor DC mediante un puente H (TB6612FNG). La lógica de PWM es:

- **Velocidad positiva (0 a 150)**: PWM variable en pinMotor1, PWM fijo en pinMotor2
- **Velocidad negativa (-150 a 0)**: PWM fijo en pinMotor1, PWM variable en pinMotor2
- **Velocidad 0**: Ambos motores en LOW

```cpp
if (velocidad > 0) {
    int pwmResta = 150 - velocidad; 
    analogWrite(pinMotor1, 150);      // PWM fijo
    analogWrite(pinMotor2, pwmResta); // PWM variable
}
```

Esta técnica permite un control de velocidad suave y mantiene el torque constante.

#### 2. Manejo de Comandos Seriales

El bucle principal escucha constantemente el puerto serial y procesa comandos:

```cpp
if (Serial.available() > 0) {
    String entrada = Serial.readStringUntil('\n');
    char tipoComando = toupper(entrada.charAt(0));
    
    if (tipoComando == 'S') {
        int angulo = entrada.substring(1).toInt();
        miServo.write(constrain(angulo, 30, 90));
    }
    else if (tipoComando == 'M') {
        int velocidad = entrada.substring(1).toInt();
        fijarMotor(velocidad);
    }
}
```

## Solución de problemas comunes

### No se conecta al puerto serial /dev/ttyUSB0 o /dev/ttyACM0

Verifica que el Arduino está conectado y reconocido:

```bash
lsusb
ls -l /dev/ttyACM0
```

Si no tienes permisos, ejecuta:

```bash
sudo chmod 666 /dev/ttyACM0
sudo usermod -a -G dialout $USER
```

### ROS 2 no encuentra el paquete o el nodo

Asegúrate de haber hecho source del workspace:

```bash
source ~/wro_ws/install/setup.bash
```

Verifica que el nombre del paquete y del ejecutable coinciden en `setup.py`. Recompila si es necesario:

```bash
colcon build --packages-select wro_reto_abierto
```

### El servo no responde o los motores no giran

Comprueba que el Arduino recibe los comandos. Abre el monitor serial en el Arduino IDE (a 115200 baudios) y envía manualmente `S45` y `M20` para ver si hay respuesta. Verifica la conexión de los cables y que los límites del servo sean correctos (30-90).

### Las lecturas del LiDAR son erróneas

Asegúrate de que el tópico `/scan` se publica correctamente:

```bash
ros2 topic echo /scan
```

Comprueba que los rangos de ángulos en el código coinciden con la orientación del LiDAR. Puedes modificar los límites (75-105, 165-195, 345-15) según la posición del sensor.

### El robot gira en sentido incorrecto

Revisa la lógica de `detectarlado_en_pared()`. Si la pared derecha está más cerca, `sentido=2` (gira a la derecha). Para invertir el comportamiento, intercambia los valores.

---

## Recomendaciones finales

- **Prueba los comandos por separado**: antes de ejecutar el nodo completo, verifica que el Arduino responde a comandos manuales desde el monitor serial y que el LiDAR publica datos correctamente.
- **Ajusta los parámetros PID**: los valores de `Kp_dist`, `Kd_dist`, etc. dependen de la velocidad y características físicas del robot. Puedes modificarlos en tiempo real con `ros2 param set`.
- **Usa `rqt_graph`** para visualizar los nodos y tópicos: `rqt_graph`.
- **Guarda los logs**: redirige la salida a un archivo con `ros2 run wro_reto_abierto wro_node > logs.txt 2>&1`.

# Videos
## Video Actual Reto 1
Reto abierto Red Machine 2026 (https://www.youtube.com/watch?v=zJ_OKyx9S7s)

## Video Actual Reto 2
[](https://youtu.be/Ffp2MwC_Hfk?si=NL7WM5FfkNmI31rE)

## Videos del robot versión 1.0
### Primer reto (prueba abierta)
[](https://youtu.be/W26b5g69BQQ?si=Y7qg7TaV6iR0McLb)

### Segundo reto (prueba cerrada)
[](https://youtube.com/shorts/cc8yKOo6g8U?si=XeC0w1IYvneSmaU0)

## Videos del robot versión 2.0

### Video del Reto 1, Todas las Variantes
[
](https://www.youtube.com/watch?v=HS7eLoFSOkU)

### Video del reto 2 completo 
[
](https://www.youtube.com/watch?v=cjjnRDXaDAU&t=56s)

## Videos del robot
### Demostración de Detección de Color
[
](https://www.youtube.com/shorts/HLt_O2JlURQ)

### Prueba de Continuidad
[](https://www.youtube.com/shorts/jUmZjaQ_be8)

## Videos sobre Red Machine
### Presentación Nacional 2023
[](https://www.youtube.com/watch?v=fVg6WCavaBU)
### Red Machine Nacional 2023
[](https://www.youtube.com/watch?v=FSo2NadI6ec&pp=0gcJCbIJAYcqIYzv)
### Presentación de Red Machine
[](https://www.youtube.com/watch?v=EYFYI9Z96V4&t=25s)
### Robótica educacional
[](https://www.youtube.com/watch?v=Is-765hQCRY)

# Historia y Cronología de Red Machine

1. Resumen del diseño evolutivo del robot
2. Temporada 2023
- [Julio 2023](https://github.com/Samu4035/REDMACHINE-2025/blob/main/t-photos/Historia.md#Julio-2023)
- [Agosto 2023](https://github.com/Samu4035/REDMACHINE-2025/blob/main/t-photos/Historia.md#Agosto-2023)
- [Septiembre 2023](https://github.com/Samu4035/REDMACHINE-2025/blob/main/t-photos/Historia.md#Septiembre-2023)
- [Octubre 2023](https://github.com/Samu4035/REDMACHINE-2025/blob/main/t-photos/Historia.md#Octubre-2023)
3. Temporada 2024
- [Febrero 2024](https://github.com/Samu4035/REDMACHINE-2025/blob/main/t-photos/Historia.md#Febrero-2024)
- [Marzo 2024](https://github.com/Samu4035/REDMACHINE-2025/blob/main/t-photos/Historia.md#Marzo-2024)
- [Abril 2024](https://github.com/Samu4035/REDMACHINE-2025/blob/main/t-photos/Historia.md#Abril-2024)
- [Mayo 2024](https://github.com/Samu4035/REDMACHINE-2025/blob/main/t-photos/Historia.md#Mayo-2024)
- [Junio 2024](https://github.com/Samu4035/REDMACHINE-2025/blob/main/t-photos/Historia.md#Junio-2024)
- [Octubre 2024](https://github.com/Samu4035/REDMACHINE-2025/blob/main/t-photos/Historia.md#Octubre-2024)
- [Noviembre 2024](https://github.com/Samu4035/REDMACHINE-2025/blob/main/t-photos/Historia.md#Noviembre-2024)
4. Temporada 2025
- [Febrero 2025](https://github.com/Samu4035/REDMACHINE-2025/blob/main/t-photos/Historia.md#Febrero-2025)
- [Marzo 2025](https://github.com/Samu4035/REDMACHINE-2025/blob/main/t-photos/Historia.md#Marzo-2025)
- [Abril 2025](https://github.com/Samu4035/REDMACHINE-2025/blob/main/t-photos/Historia.md#Abril-2025)
- [Mayo 2025](https://github.com/Samu4035/REDMACHINE-2025/blob/main/t-photos/Historia.md#Mayo-2025)
5. Julian, Luka y Pompo
- [JULIAN 1.0](https://github.com/Samu4035/REDMACHINE-2025/blob/main/t-photos/Historia.md#JULIAN-1.0)
- [JULIAN 2.0](https://github.com/Samu4035/REDMACHINE-2025/blob/main/t-photos/Historia.md#JULIAN-2.0)
- [JULIAN 3.0](https://github.com/Samu4035/REDMACHINE-2025/blob/main/t-photos/Historia.md#JULIAN-3.0)
- [JULIAN 4.0](https://github.com/Samu4035/REDMACHINE-2025/blob/main/t-photos/Historia.md#JULIAN-4.0)
- [JULIAN 5.0](https://github.com/Samu4035/REDMACHINE-2025/blob/main/t-photos/Historia.md#JULIAN-5.0)
- [LUKA 1.0](https://github.com/Samu4035/REDMACHINE-2025/blob/main/t-photos/Historia.md#LUKA-1.0)

- [LUKA 2.0](https://github.com/Samu4035/REDMACHINE-2025/blob/main/t-photos/Historia.md)

- [LUKA 3.0](https://github.com/Samu4035/REDMACHINE-2025/blob/main/t-photos/Historia.md#LUKA-3.0)

- [POMPO 1.0](https://github.com/Samu4035/REDMACHINE-2025/blob/main/t-photos/Historia.md#POMPO-1.0)

- [POMPO 2.0](https://github.com/Samu4035/REDMACHINE-2025/blob/main/t-photos/Historia.md#POMPO-2.0)

- [POMPO 3.0](https://github.com/Samu4035/REDMACHINE-2025/blob/main/t-photos/Historia.md#POMPO-3.0)

## Resumen del diseño evolutivo del robot
El diseño actual del robot se debe a un avance continuo basado en los resultados de prototipos anteriores. Este avance nace en la primera temporada en la que el equipo participó (2023), y ha continuado evolucionando a lo largo de las temporadas. Esto se puede observar con mayor detalle en la cronología que sigue luego de este corto resumen. 
Los mayores cambios observables en los prototipos se basan en datos experimentales en el funcionamiento y estabilidad en el robot. Las mayores diferencias entre robots son: 
- **Julian (2023) -> Luka (2024):**
1. ESP32-cam a webcam a pixycam: Desde que el equipo comenzo a trabajar en el segundo reto se mantuvo un constante problema en el principio, la deteccion de los obstaculos de la ronda cerrada. Debido a las dificultades y limitaciones de trabajar con ESP32-cam, al comenzar la siguiente temporada se comenzo a trabajar con una webcam usando opencv.
A pesar de que el funcionamiento con la webcam era muy superior, seguia siendo deficiente durante la transmicion de la informacion, por lo que se decidio migrar a un sistema mucho mas simple de manejar, pixycam con arduino, el cual fue la mejor opcion para el equipo durante un largo tiempo.
2. Cambios estructurales: Uno de los mayores problemas de Julian era su gran tamaño, que dificultaba la maniobrabilidad en la pista. Luka se diseño para ser mucho mas compacto obteniendose una gran mejora. 

- **Luka (2024) -> pompo (2025):**
1. Cambios estructurales: Tanto la estructura de julian como la de luka eran diseñadas con cortes de acrilico, lo que dificultaba mucho la precisión en sus componentes mecanicos dificultando la estabilidad en la pista. Al trabajar con pompo se utilizaron piezas de lego disminuyendo en un gran porcentaje este problema.

- **pompo (2025) -> pompo (2026):**
1. Cambios estructurales: Buscando maximizar la precision mecanica y buscando asimismo tener mayor libertad en el diseño del robot, se paso de trabajar de lego a trabajar con impresion 3D para el chasis y las diversas estructuras de pompo.
2. Cambios en traccion: En los primeros prototipos se utilizo un motor rev robotics el cual era muy pesado, por lo que al trabajar en este nuevo prototipo se utilizan motores mas livianos que permiten obtener la misma estabilidad minimizando el peso del robot.
3. Cambios de componentes: Se paso de utilizar sensores de ultrasonido a utilizar un sensor lidar para las distintas detecciones que debe realizar el robot durante su estancia en la pista. 

- **Cambios generales:**
1. Estructurales: Durante todos los modelos se realizaron cambios para aumentar la precision de los movimientos y disminuir el peso de la estructura
2. Componentes: El equipo ha utilizado diversos sensores a lo largo de los avances, buscando una mejor deteccion, comunicacion con el cerebro, y consistencia en los resultados. Asi mismo tambien el equipo ha trabajado con dos placas principales: arduinos y raspberry pi, siendo esta ultima el principal controlador del robot actual.
3. Programacion: Han cambiado programas, metodos, plataformas, etc, utilizando las que mejor permiten comunicarse con las placas. 

## Temporada 2023

### Julio 2023

Después de participar en una competencia regional de robótica, el equipo decidió participar en la WRO, específicamente en la categoría Future Engineers. Como primer paso, el equipo comenzó a estudiar y analizar las reglas de la competencia.

1ra julio

En los días siguientes, el equipo comenzó a estudiar lo que podría ser la primera versión del chasis e investigó varias formas de abordar los retos iniciales, que consistían en cómo diseñar el sistema de dirección y qué motor utilizar para lograr la velocidad y el par (torque) requeridos.

2da julio

A continuación, el equipo comenzó a buscar motores que pudieran utilizarse, desarmando juguetes, impresoras y otros dispositivos, obteniendo finalmente el motor necesario al desmantelar un coche a control remoto Nikko Dodge T-rex Ram, lo que proporcionó las piezas mecánicas necesarias para diseñar el sistema de dirección.

3rajulio 

4julio

Posteriormente, el equipo procedió a ensamblar ambos sistemas, junto con los diversos dispositivos que el robot necesitaría, sobre bases de acrílico, completando el primer prototipo de lo que se convertiría en el chasis y permitiéndoles avanzar con la fase de programación.

5julio

Para la programación, se utilizó un Arduino Mega 2560 como controlador, un puente H dual como regulador de potencia y velocidad, y un sensor ultrasónico para medir la distancia. Posteriormente, el equipo reanudó la búsqueda de soluciones para detectar los colores del semáforo, decidiendo utilizar una ESP32-CAM con una lente OV2640, siendo el siguiente desafío cómo programarla con Arduino.

6julio

El equipo investigó qué fuente de alimentación utilizar para el robot, ya que tras usar baterías de 9V, se dieron cuenta de que no eran ideales ya que se agotaban muy rápidamente. En consecuencia, se conectaron dos paquetes de baterías, cada uno conteniendo ocho celdas recargables de 1.2V en serie, proporcionando finalmente un total de 9.6V.

Debido a requerimientos de espacio, se diseñó un segundo prototipo, añadiendo un segundo nivel al robot. La electrónica se colocó en el nivel superior, mientras que el primer nivel albergó las baterías, el sistema de tracción y el sistema de dirección.
7julio

Sin poder resolver la programación todavía, se decidió utilizar un sensor RGB 34725 para que el robot pudiera detectar en qué dirección debía cruzar.

8julio

Se propuso una estrategia: se decidió cruzar detectando el color de las líneas de la pista, utilizando también dos sensores ultrasónicos adicionales, uno a cada lado del robot, para que una vez que detectara una pared, pudiera cruzar para evitar una colisión. Sin embargo, estos dos sensores ultrasónicos terminaron siendo más un problema que una ayuda, porque cuando detectaban algo, el robot perdía su trayectoria. En consecuencia, finalmente se decidió no utilizar estos dos sensores ultrasónicos.

9julio

Antes de la competencia, el equipo encontró baterías recargables con un voltaje mayor (3.7 V), por lo que se decidió retirar uno de los dos paquetes de baterías y modificar el paquete restante para operar con 3 baterías.

10julio

### Agosto 2023

Después de participar en la primera competencia regional, el equipo comenzó a buscar soluciones a los problemas encontrados. Se decidió cambiar el sistema de dirección, creando uno nuevo utilizando piezas de un kit de robótica Spike Prime, número 45678, ya que este nuevo sistema de dirección permitiría un radio de giro mayor así como giros más precisos.

1ago

Se propusieron nuevas estrategias, para las cuales se decidió que la manera ideal de cruzar sería con la ayuda de sensores ultrasónicos, y que el sensor TCS34725 solo detectaría la primera línea para determinar si el robot debía cruzar en sentido horario o antihorario.

Continuando con la segunda parte del reto, el equipo comenzó a programar la cámara, buscando una forma de transferir la información de la cámara al Arduino sin utilizar Wi-Fi. Tras investigar varias fuentes, encontraron una solución: transmitir los datos a través de puertos serie.

Luego, el motor utilizado durante todo este tiempo comenzó a fallar frecuentemente, impidiendo que el equipo avanzara en el segundo reto. Pocos días antes de la competencia, el equipo extrajo el motor —y en consecuencia la caja de cambios— de otro coche a control remoto para integrarlo en el robot.

2ago

Para proporcionar un radio de giro mayor, el sistema de dirección se modificó utilizando piezas de un kit Lego Spike Prime.

3ago

### Septiembre 2023

Se realizaron sesiones de práctica en la pista para mejorar el rendimiento del robot en los retos uno y dos, con el objetivo de obtener los mejores resultados en el campeonato nacional 2023. Se redactó y actualizó el informe basándose en el progreso alcanzado hasta el momento, seguido de prácticas adicionales en la pista para mejorar aún más el rendimiento del robot en los retos uno y dos para el campeonato nacional 2023.

4ago 5 ago

Ha llegado el momento de la competencia nacional, donde el equipo logró con éxito el objetivo de clasificar para la Copa Mundial WRO 2023 en Panamá.

sep2sep1

### Octubre 2023

Se continuó trabajando en la programación de la cámara para el Reto 2. Se cambiaron las ruedas del sistema de dirección para mejorar la seguridad y la estética, y comenzó la construcción del tercer prototipo del robot, centrándose en restaurar las piezas de acrílico y organizar los cables mediante conectores para mejorar la apariencia general del robot.

sep3

Llega el momento de la Copa Mundial, donde el equipo se posicionó entre los 25 mejores del mundo y dentro de los 2 primeros entre los países latinoamericanos.

oc1oct2

## Temporada 2024

### Febrero 2024

Lo primero que hizo el equipo para iniciar esta temporada fue estudiar el nuevo reglamento, para identificar las diferencias en el reto y considerar posibles estrategias para el nuevo año.

febrero 1

El equipo comenzó a diseñar el nuevo robot, teniendo en cuenta todo lo aprendido en la Copa Mundial. Durante esta fase de diseño, se consideraron aspectos como el tamaño, el peso, qué componentes se utilizarían, su ubicación y la distancia entre los sistemas de tracción y de dirección.

feb2

El equipo continuó planificando qué estrategia utilizar. Para evitar revelar las mejoras y avances planeados para el nuevo robot, decidieron que lo mejor sería competir con Julián (el robot de 2023) durante las competencias regionales y utilizar el nuevo robot (Luka) en la competencia nacional, que sería el mayor desafío en ese momento.

feb3

### Marzo 2024

Durante este mes, comenzó la construcción del robot para la competencia nacional de 2024. En la primera semana de marzo, se cortaron las bases de acrílico y se compraron los componentes faltantes para el robot.  

Primero, se instalaron el sistema de tracción y el sistema de dirección en el robot. En esta etapa, el sistema de dirección se construyó utilizando tres piezas de acrílico. Después, se instalaron el Arduino y la Raspberry Pi.

feb4feb5

A finales de marzo, se completó la construcción del robot tras instalar todos los sensores que utilizaría. Asimismo, se inició la programación para el Reto 1, junto con la programación en Python para el Reto 2.

feb6

### Abril 2024

Dado que el equipo decidió participar con Julián en las competencias regionales, se comenzó a trabajar en algunas mejoras para el rendimiento del robot. Una de estas mejoras fue reemplazar el sensor RGB 34725 por el sensor de color TCS3200.

feb7

En preparación para la próxima competencia regional, se actualizó el informe de acuerdo con el trabajo realizado hasta el momento. Las actualizaciones más importantes incluyeron la cronología, el diagrama de cableado y las especificaciones del sensor de color.

feb8

Competencias Regionales de 2024:

Colegio Santo Tomás de Aquino 05-04-2024
feb9

### Mayo 2024
Liceo Los Robles 05-18-2024
feb10

### Junio 2024

En preparación para la competencia nacional, el equipo continuó realizando pruebas en ambos retos, centrándose principalmente en el segundo; al mismo tiempo, trabajaron en el informe de Luka.

Durante las pruebas, se decidió retirar el sensor de color, ya que no funcionaba de manera óptima, y se comenzaron a utilizar los sensores ultrasónicos laterales para determinar qué camino debía seguir Luka.

jun1

El equipo logró completar el informe en su totalidad y terminó de subir toda la información a GitHub a finales de mes, quedando completamente preparado para la competencia nacional de la WRO 2024.

JUN2 JUN3

### Octubre 2024

Tras ganar la competencia nacional, el equipo logró formar parte de la delegación que representó a Venezuela en la final internacional de la Olimpiada de Robótica en Esmirna, Turquía. Esto requirió una extensa preparación y práctica, por lo que comenzaron a trabajar en Luka.

Durante las primeras dos semanas de preparación, el equipo comenzó a realizar cambios estructurales en Luka para reducir el tamaño del robot. Para lograrlo, se modificaron tanto el sistema de tracción como el de dirección. El sistema de dirección se giró 180 grados para que las ruedas quedaran posicionadas más hacia el frente, y el motor de tracción se reposicionó verticalmente para ocupar menos espacio horizontal. Tras esto, se eliminaron aproximadamente 5 cm de espacio no utilizado en la parte trasera del robot, completando este proceso con un robot de 18 cm de longitud.

motor comparation
Traction comparation

La tercera semana de trabajo marcó el inicio de la programación. Tras encontrar problemas con la alimentación de la Raspberry Pi, el equipo decidió buscar un método nuevo para detectar las señales de tráfico. Después de evaluar soluciones, optaron por utilizar una Pixy Cam debido a que ocupaba menos espacio, pesaba menos y podía alimentarse directamente del Arduino. El equipo también se dio cuenta de que un giróscopo sería necesario, especialmente para el segundo reto, por lo que comenzaron a utilizar el magnetómetro HMC5883L.

pixy2 1
HMC5883L

La Pixy Cam resultó ser una excelente opción, pero el magnetómetro no lo fue, por lo que el equipo comenzó a buscar uno nuevo y eligió el MPU6050. Tras extensas prácticas con el acelerómetro, el equipo pudo utilizarlo en curvas completas, pero debido a su gran margen de error, no podían depender de él para hacer que el carro girara exactamente 90 grados.

prueba pixy
MPU6050

Por lo tanto, el equipo aprovechó la cuarta semana para diseñar una nueva estrategia. Con esta nueva estrategia, el robot se calibró utilizando las paredes exteriores.

### Noviembre 2024

La primera semana de noviembre se dedicó por completo a la preparación y la práctica. Durante esta semana, el robot logró completar dos vueltas consistentes en el segundo reto, pero el equipo seguía preocupado por el problema del giróscopo.

ramdom practice

En la segunda semana de noviembre, el equipo comenzó a practicar con un nuevo giróscopo, el BNO055. Este sensor es un híbrido entre un magnetómetro y un acelerómetro, lo que le permite proporcionar datos casi exactos.

BNO055

Finalmente, los días 28, 29 y 30 de noviembre de este mes, el equipo compitió en la final internacional en Turquía, logrando el puesto 19 a nivel mundial y el segundo lugar en América Latina.

"FOTO"

Esta competencia dejó al equipo altamente motivado para las próximas competencias nacionales, con el objetivo de clasificar y lograr los mejores resultados en la final internacional que se celebrará en Singapur.



## Temporada 2025

### Febrero 2025

Como cada año, la primera acción de Red Machine al iniciar una nueva temporada fue revisar los cambios en el reglamento y la puntuación de la competencia. El equipo estudió minuciosamente las nuevas reglas para garantizar que todo el trabajo estuviera en plena conformidad con ellas, permitiendo así desarrollar y construir el mejor robot posible.

Bajo estas directrices, durante las semanas siguientes de este primer mes, se dio inicio a la creación del primer prototipo del nuevo robot, bautizado como "Pompo".

### Marzo 2025

Este mes, el equipo finalizó el primer prototipo de Pompo y comenzó con la programación, utilizando ROBOTC como entorno para programar el módulo EV3, el cual funcionaba como el cerebro de este primer prototipo.

Tras largas sesiones de práctica, el equipo completó el primer reto a la perfección, por lo que llegó el momento de pasar al segundo. En este punto, el equipo se enfrentó a un problema importante: adaptar la Pixy Cam a este módulo EV3.

### Abril 2025

Tras dedicar tiempo a buscar soluciones a este inconveniente, el equipo determinó que lo más conveniente era regresar a trabajar con Arduino, ya que la programación es muy similar y el problema actual se podía resolver con mucha mayor rapidez.

A partir de esta decisión, trabajaron intensamente durante un largo periodo para modificar todo el chasis del robot y adaptarlo a Arduino, así como a los nuevos sensores y motores que se utilizarían, debido a que los componentes de EV3 no son directamente compatibles con Arduino.

Una vez finalizada la construcción, el equipo retomó la programación, pero al probar a Pompo en la pista, su chasis comenzó a presentar fallas de funcionamiento.

### Mayo 2025

Por esta razón, el equipo retomó el trabajo en la mejora del chasis, logrando finalmente consolidar el que sería el primer chasis definitivo de Pompo.

La programación del primer reto avanzó con rapidez, por lo que el trabajo en el segundo reto comenzó casi de inmediato.

## Julian, luka and pompo

## Decisiones de Ingeniería

### Filosofía de Diseño y Estrategia

1.  **Gestión Estratégica de Plataformas:**
    - **Decisión:** El equipo decidió competir con el robot del año anterior (Julián) durante las competencias regionales, para no revelar las mejoras y avances de la nueva plataforma (Luka), reservando el robot nuevo para la competencia nacional (2024).
    - **Fundamento:** Esta decisión estratégica protegió la propiedad intelectual y las mejoras técnicas del nuevo diseño, evitando que fueran expuestas prematuramente a los competidores, y permitió disponer de más tiempo de desarrollo para la nueva plataforma antes de una competencia de alto calibre.

2.  **Arquitectura Modular y Escalabilidad:**
    - **Decisión:** El equipo adoptó un diseño de chasis de dos niveles, separando los componentes de alta potencia (baterías, sistema de tracción) de la electrónica sensible (controladores, sensores).
    - **Fundamento:** Este enfoque modular fue fundamental para reducir la interferencia electromagnética (EMI), mejorar la gestión térmica y facilitar la creación rápida de prototipos y la depuración. Permitió actualizar de forma independiente el sistema de potencia y los subsistemas de control, como se demuestra en el desarrollo iterativo de Julián a Luka.

### Sistema de Alimentación

3.  **Optimización de la Fuente de Alimentación:**
    - **Decisión:** El equipo pasó de utilizar baterías estándar de 9 V a paquetes de baterías personalizados, empleando inicialmente 8 celdas NiMH de 1,2 V (9,6 V) y optimizando posteriormente con celdas de Li-ion de 3,7 V de alta capacidad.
    - **Fundamento:** Esta fue una decisión crítica para el presupuesto energético. Las baterías de 9 V iniciales se identificaron como una debilidad importante debido a su alta resistencia interna y rápida caída de tensión, lo que provocaba inestabilidad en el sistema. Los paquetes personalizados proporcionaron la corriente necesaria para los motores y un voltaje estable para el microcontrolador y los sensores durante toda la prueba.

4. **Sustitución del Puente H L298N por el Driver MOSFET Dual TB6612FNG:**
   - **Decisión:** Abandonar el antiguo módulo L298N y adoptar el puente H TB6612FNG para controlar los motores de tracción.
   - **Fundamento:** El L298N (bipolar) generaba caídas de tensión internas de ~2 V y altas pérdidas por calor. El TB6612FNG cuenta con etapas MOSFET de muy baja resistencia ($R_{DS(on)}$), ofreciendo alta eficiencia energética, respuesta lineal a frecuencias PWM de hasta 100 kHz y un tamaño drásticamente reducido.  

5. **Aislamiento Eléctrico del Servomotor con Regulador LM2596 Dedicado (6.0 V):**
   - **Decisión:** Instalar un convertidor Step-Down LM2596 independiente ajustado a 6.0 V para alimentar únicamente el servomotor REV Robotics.
   - **Fundamento:** El servomotor de dirección de alto torque (13.5 kg-cm) demanda picos repentinos de corriente durante virajes rápidos. Separar su línea de alimentación de la de 5 V lógica evita ruidos inductivos y descensos bruscos de voltaje (brownouts) que reiniciarían la Raspberry Pi 5 o desincronizarían el LiDAR.

6. **Suministro Lógico de Alta Capacidad con Regulador XL4015 (5 V / 5 A):**
   - **Decisión:** Incorporar un regulador conmutado XL4015 de 5 A / 96% de eficiencia para energizar la línea principal de 5 V DC.
   - **Fundamento:** La Raspberry Pi 5, la webcam HD, el LiDAR ST27L y el Arduino Uno superan en conjunto los 1.6 A continuos, con picos de demanda mayores a 3.5 A. Los reguladores genéricos de 3 A provocaban reinicios por subvoltaje, mientras que el XL4015 proporciona energía limpia e ininterrumpida.

### Diseño Mecánico, Fabricación Digital y Materiales

7.  **Selección de Actuadores y Reducción de Engranajes:**
    - **Decisión:** El equipo obtuvo motores y cajas de cambios de coches teledirigidos comerciales (por ejemplo, Nikko Dodge T-rex Ram) y más adelante exploró soluciones personalizadas.
    - **Fundamento:** Esta fue una decisión de rendimiento frente a coste. Recuperar motores y cajas de cambios de vehículos teledirigidos de alto par proporcionó una solución probada y rentable para alcanzar la velocidad y el par necesarios para las tareas de la competición, reduciendo la necesidad de fabricación mecánica compleja y personalizada en las primeras fases del ciclo de desarrollo.

8. **Selección de PETG para la Fabricación en Creality K1 Max (frente a PLA/ABS):**
   - **Decisión:** Estandarizar la fabricación aditiva de todas las placas del chasis en filamento PETG (impreso a 240-245 °C de boquilla y 70-80 °C de cama).
   - **Fundamento:** El PLA demostró ser demasiado frágil ante impactos; el ABS presentaba deformación por contracción (warping) en piezas planas largas; el Nylon requería un procesamiento higroscópico complejo. El PETG ofreció el balance ideal entre resistencia mecánicamente elástica, tenacidad contra impactos y estabilidad dimensional.

9. **Geometría y Diferenciación Técnica del Tren de Ruedas:**
   - **Decisión:** Implementar ruedas Lego Technic medianas de banda ancha ($49.5 \times 20\text{ mm}$) en el eje trasero y ruedas pequeñas de bajo perfil con menor trocha en el eje delantero.
   - **Fundamento:** La amplia huella trasera maximiza el agarre y la transferencia de torque de los motores DC para evitar patinaje. El perfil estrecho delantero reduce la resistencia a la rotación lateral, disminuye la carga sobre el servomotor y evita el sobreviraje (drifting) en curvas cerradas.

10. **Inversión de Orientación de los Motores Traseros (Iteración de Chasis 5.1):**
   - **Decisión:** Invertir la posición física de montaje de los motores de tracción DC en las cavidades del piso base durante las pruebas de rodaje del chasis.
   - **Fundamento:** En los primeros ensayos, el robot presentaba inestabilidad dinámica al acelerar. La inversión geométrica de los motores corrigió la distribución de masa sobre el eje de tracción, eliminando los derrapes sin necesidad de añadir contrapesos mecánicos.

### Estándares de Cableado y Mantenimiento

11. **Estandarización de Código de Colores y Trenzado EMI:**
   - **Decisión:** Implementar un código estricto de colores por función (Rojo: Positivo, Negro: GND, Azul: PWM, Amarillo/Verde: Comunicación) y trenzar por pares los cables de corriente principal.
   - **Fundamento:** En temporadas anteriores la falta de código de colores ralentizaba la reparación en boxes. El trenzado de pares de potencia cancela por acoplamiento magnético la interferencia electromagnética (EMI) emitida hacia las líneas de datos de los sensores.

12. **Protección con Tubo Termorretráctil (Thermoshrink) y Alivio de Tensión Mecánica:**
   - **Decisión:** Reemplazar la cinta aislante por tubo termorretráctil en soldaduras e integrar bucles de curvatura fija en los cables de componentes móviles (como el servomotor).
   - **Fundamento:** Evita cortocircuitos por degradación de adhesivos y garantiza que el esfuerzo mecánico de los movimientos de dirección sea absorbido por la estructura del chasis impreso en PETG y no por los pines o conectores del sensor.

### Sistemas de Navegación y Sensores

13.  **Arquitectura del Sistema de Visión (Evolución y Retrospectiva):**
    - **Decisión:** El equipo migró de una ESP32-CAM con lente OV2640 a una cámara Pixy2.
    - **Fundamento:** Esta decisión se basó en la latencia, la facilidad de integración y el presupuesto energético. La solución con ESP32-CAM, aunque potente, requería una comunicación serie compleja que introducía latencia. La Pixy2 ofreció una ventaja significativa: se trataba de un sistema de visión integrado y dedicado con una interfaz UART/SPI sencilla y podía alimentarse directamente desde el Arduino, simplificando la arquitectura electrónica y reduciendo la carga de procesamiento en el controlador principal.

14.  **Estimación de Estado y Navegación Inercial:**
    - **Decisión:** El equipo adoptó un enfoque sofisticado de fusión de sensores, evolucionando de un magnetómetro simple (HMC5883L) a un acelerómetro/giróscopo MPU6050, y finalmente a un sensor de orientación absoluta BNO055.
    - **Fundamento:** Esta fue una decisión crucial para resolver los problemas de deriva y precisión en el segundo reto. El MPU6050, aunque suponía una mejora, sufría una deriva significativa del giroscopio y errores de integración, lo que impedía realizar giros precisos de 90 grados. El BNO055, al combinar un magnetómetro y un acelerómetro, proporciona datos casi exactos, eliminando la deriva y permitiendo una navegación fiable y repetible.

15. **Transición de Sensores Ultrasónicos a LiDAR dToF Omnidireccional (LDROBOT ST27L):**
   - **Decisión:** Reemplazar los arreglos de ultrasonidos por un sensor LiDAR óptico de tiempo de vuelo directo (dToF) capaz de realizar escaneos de 360° hasta 25 metros.
   - **Fundamento:** Los ultrasonidos sufrían de rebotes falsos y un cono de detección muy limitado. El LiDAR ST27L alcanza una precisión del ~99.1%, permitiendo al algoritmo SVD trazar una recta con un 93.4% de semejanza a las paredes reales de la pista, aislando eficazmente los obstáculos (como conos o zonas de estacionamiento).

16. **Delimitación Geométrica del Campo de Visión del LiDAR (<10 cm de Altura):**
   - **Decisión:** Diseñar una pestaña elevada en el segundo piso para montar el LiDAR a aproximadamente ~10 cm del suelo, garantizando un ángulo de visión despejado de ~270°.
   - **Fundamento:** Si el LiDAR se montaba a mayor altura, el haz láser pasaba por encima de los muros perimetrales de la pista. El montaje a 10 cm alineó el plano del escáner con la altura física de las paredes, evitando al mismo tiempo que la carcasa del servomotor o las ruedas delanteras interfirieran con el láser.

### Integración y Control

17.  **Sistema de Control y Estrategia de Calibración:**
    - **Decisión:** El equipo optó por una estrategia de calibración basada en las paredes exteriores del campo de juego, en lugar de depender únicamente de datos inerciales para la navegación.
    - **Fundamento:** Ante las limitaciones de precisión de los sensores inerciales para giros exactos (especialmente con el MPU6050), se decidió utilizar referencias físicas externas (las paredes) como punto de referencia fiable. Esta decisión mejoró drásticamente la robustez y repetibilidad del robot, reduciendo la dependencia de la deriva del sensor y aumentando la fiabilidad general del sistema.

18.  **Adaptación de Plataforma (EV3 a Arduino):**
    - **Decisión:** Tras encontrar dificultades para integrar la Pixy Cam con el módulo EV3 en el prototipo Pompo 1.0, el equipo decidió volver a la plataforma Arduino para el desarrollo definitivo.
    - **Fundamento:** Esta decisión se basó en la familiaridad, la velocidad de desarrollo y la compatibilidad de componentes. El ecosistema Arduino ofrecía una curva de aprendizaje más corta, una amplia biblioteca de sensores y motores, y una comunidad de soporte más extensa, lo que permitió resolver el problema de integración de la cámara de forma mucho más ágil y continuar con el desarrollo sin interrupciones prolongadas.
    - 
### JULIAN 1.0

Primer Julian

### JULIAN 2.0

segundo julian

### JULIAN 3.0

Tercer Julian

### JULIAN 4.0

Cuarto Julian

### JULIAN 5.0

Quinto Julian

### LUKA 1.0

Primer Luka

### LUKA 2.0

Segundo Luka

### LUKA 3.0

Luka`s right

### POMPO 1.0



### POMPO 2.0



### POMPO 3.0



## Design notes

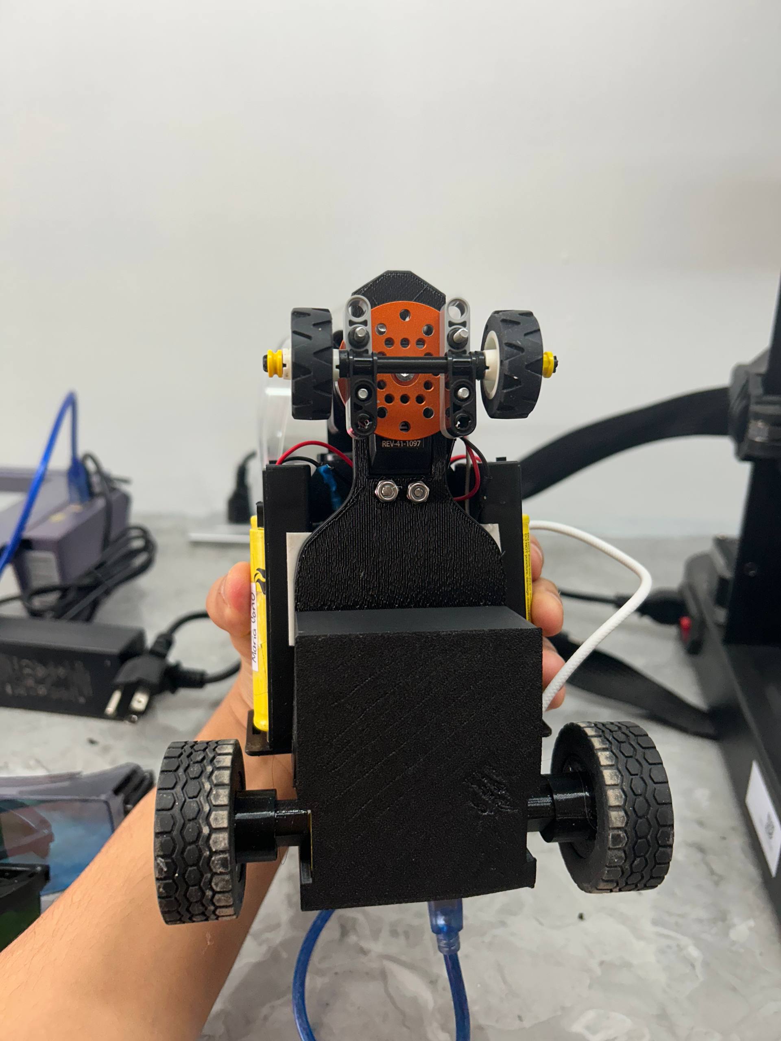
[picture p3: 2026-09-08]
v-photos/photo_4920741823874010307_w.jpg

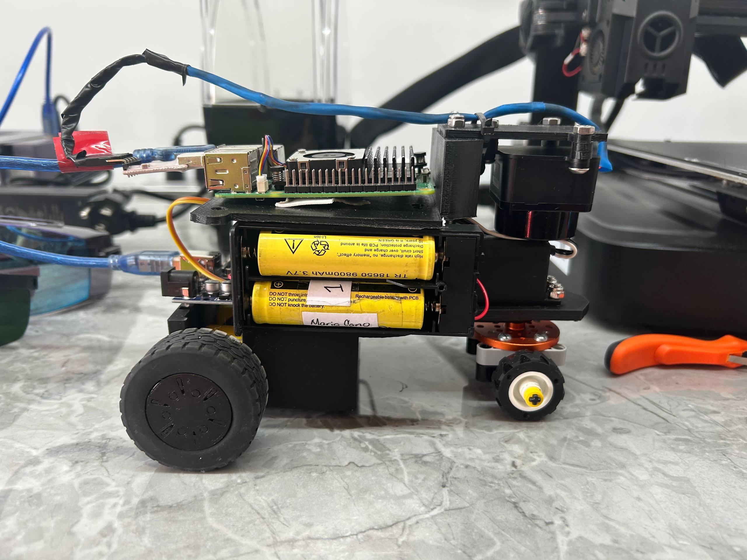
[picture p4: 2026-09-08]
v-photos/photo_4920741823874010306_w.jpg

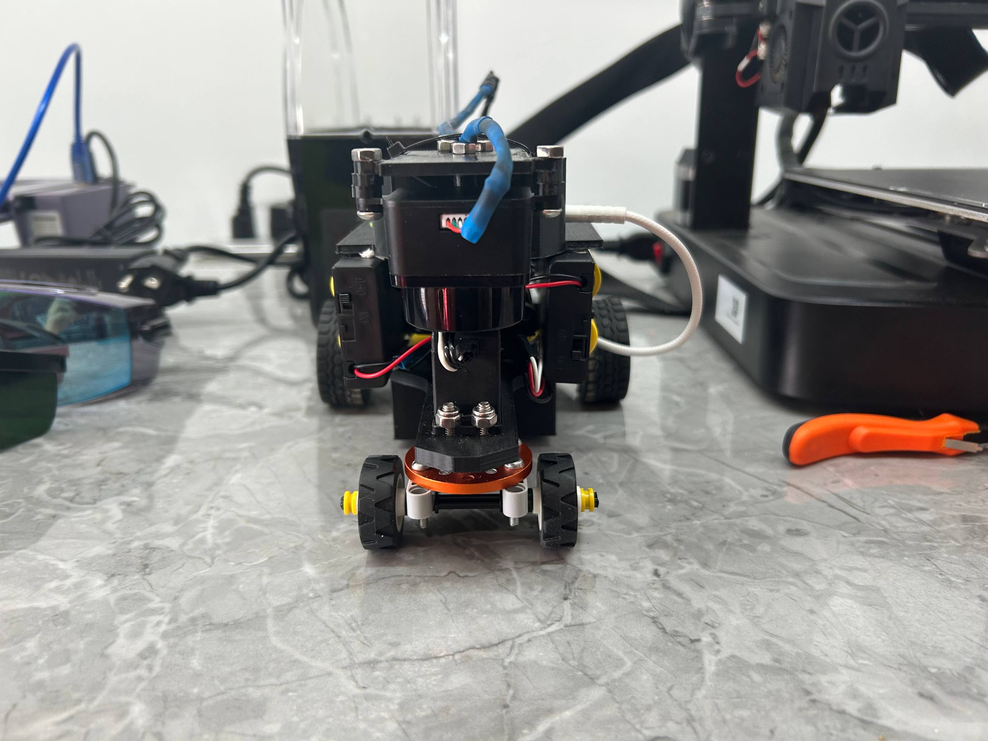
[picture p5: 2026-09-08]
v-photos/photo_4920741823874010305_w.jpg

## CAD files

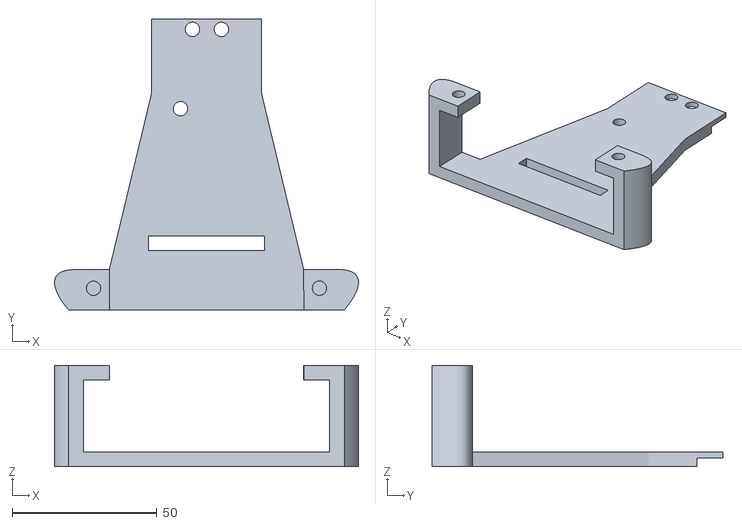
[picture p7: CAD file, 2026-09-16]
models/PISO 3.stl
105.0 x 100.5 x 35.0

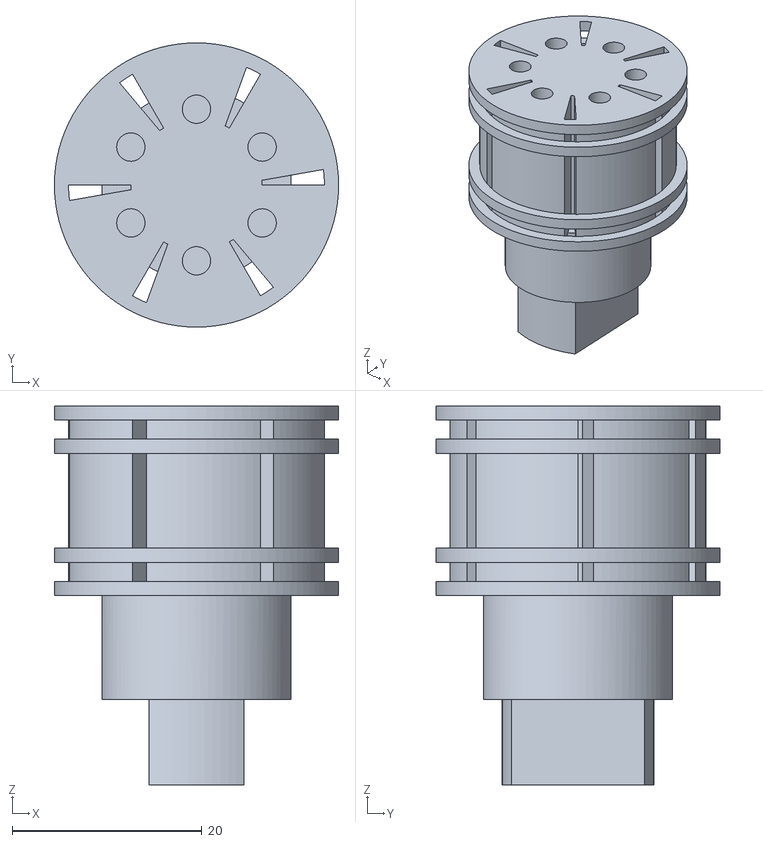
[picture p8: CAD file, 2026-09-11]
models/CONMO 2.stl
30.0 x 30.0 x 40.0

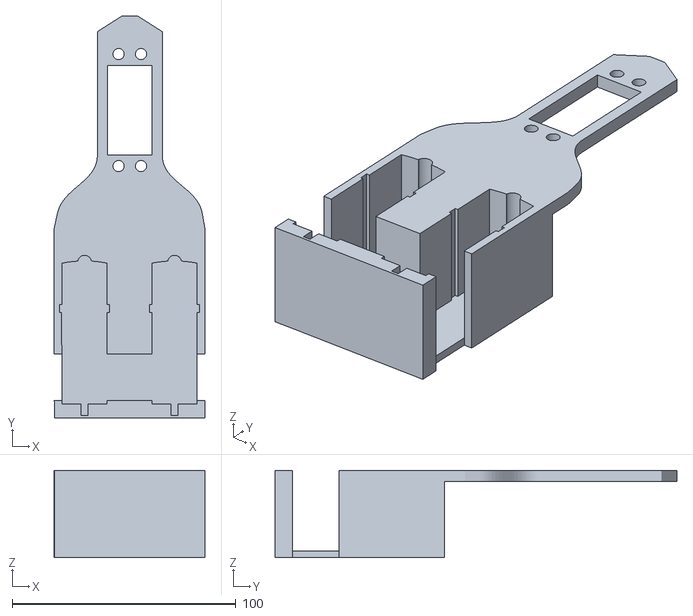
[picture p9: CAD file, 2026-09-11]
models/AGAIN 1.stl
67.3 x 179.5 x 39.0

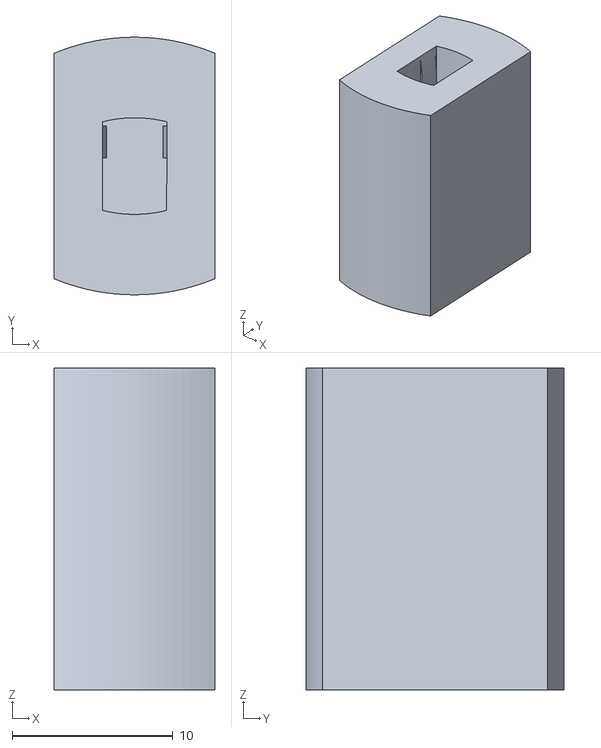
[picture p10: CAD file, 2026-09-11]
models/CONECTOR MOTOR-EJE.stl
10.00 x 16.0 x 20.0

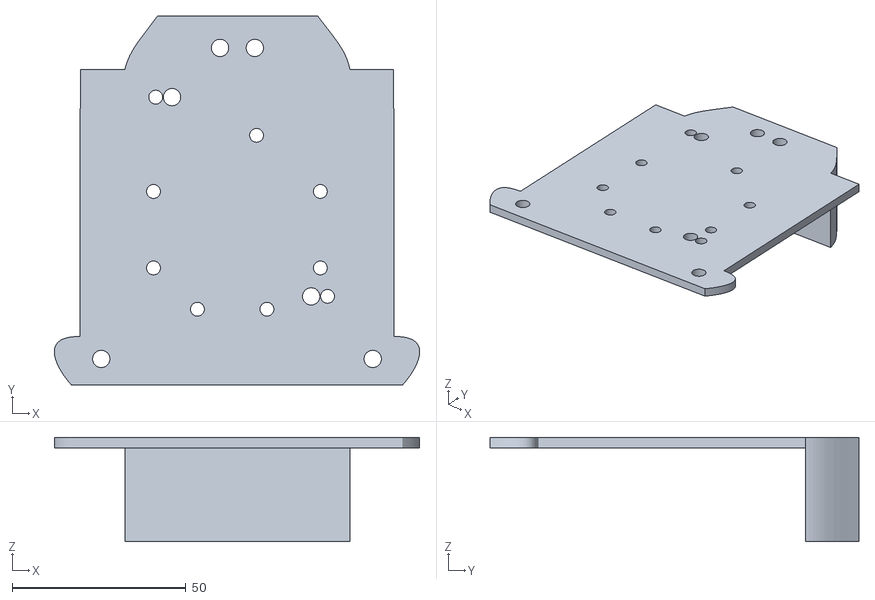
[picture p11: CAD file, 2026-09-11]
models/2DO P.stl
105.1 x 106.1 x 30.0

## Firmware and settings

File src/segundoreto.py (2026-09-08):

#!/usr/bin/env python3
import os
os.environ["QT_QPA_PLATFORM"] = "offscreen"

import rclpy
from rclpy.node import Node
from sensor_msgs.msg import LaserScan, Image
import numpy as np
import serial
import time
from collections import Counter
import cv2
from cv_bridge import CvBridge

class WroRetoAbiertoConColor(Node):
    def __init__(self):
        super().__init__('wro_reto_abierto_con_color')

        # ============================================================
        # PARÁMETROS DE NAVEGACIÓN
        # ============================================================
        self.declare_parameter('sentido', 0)
        self.declare_parameter('distancia_objetivo_base', 0.4)
        self.declare_parameter('distancia_objetivo_rojo', 0.2)
        self.declare_parameter('distancia_objetivo_verde', 0.6)
        self.declare_parameter('distancia_frontal_obstaculo', 0.45)
        self.declare_parameter('velocidad_motor', 20)
        self.declare_parameter('limite_angulo_max', 38.0)
        self.declare_parameter('umbral_error_color', 5.0)

        # PID
        self.declare_parameter('Kp_dist', 400.0)
        self.declare_parameter('Kd_dist', 40.0)
        self.declare_parameter('Ki_dist', 0.0)
        self.declare_parameter('Kp_ang', 0.0)
        self.declare_parameter('Kd_ang', 0.0)

        # Servo
        self.rec = 57
        self.izquierda = 30
        self.derecha = 90

        # Variables de distancia
        self.d = 999.0
        self.dd = 999.0
        self.di = 999.0

        self.sentido = self.get_parameter('sentido').value

        # PID memoria
        self.prev_error_dist = 0.0
        self.integral_dist = 0.0
        self.prev_error_ang = 0.0
        self.last_time = self.get_clock().now()

        # Control de giro normal (ya no se usa)
        self.girando = False
        self.tiempo_inicio_giro = 0.0
        self.TIEMPO_GIRO = 1.5

        # Finalización
        self.giros_completados = 0
        self.MAX_GIROS = 12
        self.finalizando = False
        self.tiempo_inicio_final = 0.0
        self.TIEMPO_AVANCE_FINAL = 4.0

        # ============================================================
        # MÁQUINA DE ESTADOS PARA MANIOBRA DE CRUCE
        # ============================================================
        self.cruce_activo = False
        self.cruce_fase = 0
        self.cruce_tiempo_inicio = 0.0
        self.cruce_vel = 0
        self.cruce_distancia_objetivo = self.get_parameter('distancia_objetivo_base').value

        # Último mensaje del LIDAR para usar en el cruce
        self.last_scan_msg = None

        # ============================================================
        # DETECCIÓN DE COLOR + FORMA
        # ============================================================
        self.bridge = CvBridge()
        self.frame_counter = 0
        self.process_every_n = 2

        self.declare_parameter('red_h_low1', 0)
        self.declare_parameter('red_h_high1', 7)
        self.declare_parameter('red_s_low1', 140)
        self.declare_parameter('red_s_high1', 255)
        self.declare_parameter('red_v_low1', 80)
        self.declare_parameter('red_v_high1', 255)

        self.declare_parameter('red_h_low2', 168)
        self.declare_parameter('red_h_high2', 180)
        self.declare_parameter('red_s_low2', 140)
        self.declare_parameter('red_s_high2', 255)
        self.declare_parameter('red_v_low2', 80)
        self.declare_parameter('red_v_high2', 255)

        self.declare_parameter('green_h_low', 40)
        self.declare_parameter('green_h_high', 85)
        self.declare_parameter('green_s_low', 170)
        self.declare_parameter('green_s_high', 255)
        self.declare_parameter('green_v_low', 70)
        self.declare_parameter('green_v_high', 255)

        self.declare_parameter('min_area', 300)
        self.declare_parameter('min_aspect_ratio', 1.2)
        self.declare_parameter('max_aspect_ratio', 4.0)

        self.ultimo_color = None
        self.error_angulo_actual = 0.0
        self.velocidad_actual = 0

        # ============================================================
        # CONEXIÓN CON ARDUINO
        # ============================================================
        self.puerto_serial = '/dev/ttyUSB0'
        self.baudrate = 115200
        try:
            self.arduino = serial.Serial(self.puerto_serial, self.baudrate, timeout=1)
            time.sleep(2)
            self.get_logger().info(f'✅ Conectado al Arduino en {self.puerto_serial}')
        except Exception as e:
            self.get_logger().error(f'❌ No se pudo conectar al Arduino: {e}')
            self.arduino = None

        # ============================================================
        # SUSCRIPCIONES
        # ============================================================
        self.subscription = self.create_subscription(
            LaserScan, '/scan', self.lidar_callback, 10
        )
        self.sub_image = self.create_subscription(
            Image, '/image_raw', self.image_callback, 10
        )

        self.get_logger().info('🚀 Nodo con CRUCE ESPECIAL (usando PID de navegación)')
        self.get_logger().info('📏 Cruce: retroceder 2s → girar 90° → retroceder a 5cm de pared (con PID) → avanzar')
        self.get_logger().info('🔴 ELIMINADO el giro normal a 0.45m')

    # ============================================================
    # REINICIO DE MEMORIA
    # ============================================================
    def reiniciar_memoria_color(self):
        self.ultimo_color = None
        self.get_logger().info('🔄 Memoria reiniciada (vuelve a 40 cm)')

    # ============================================================
    # FILTRO DE FORMA
    # ============================================================
    def filtrar_por_forma(self, mask):
        min_area = self.get_parameter('min_area').value
        min_aspect_ratio = self.get_parameter('min_aspect_ratio').value
        max_aspect_ratio = self.get_parameter('max_aspect_ratio').value

        contours, _ = cv2.findContours(mask, cv2.RETR_EXTERNAL, cv2.CHAIN_APPROX_SIMPLE)
        contornos_validos = []
        for cnt in contours:
            area = cv2.contourArea(cnt)
            if area < min_area:
                continue
            x, y, w, h = cv2.boundingRect(cnt)
            if w == 0:
                continue
            aspect_ratio = h / w
            if min_aspect_ratio <= aspect_ratio <= max_aspect_ratio:
                contornos_validos.append(cnt)
        return contornos_validos

    # ============================================================
    # CALLBACK DE CÁMARA
    # ============================================================
    def image_callback(self, msg):
        self.frame_counter += 1
        if self.frame_counter % self.process_every_n != 0:
            return

        umbral = self.get_parameter('umbral_error_color').value
        if abs(self.error_angulo_actual) > umbral:
            return

        try:
            cv_image = self.bridge.imgmsg_to_cv2(msg, 'bgr8')
        except Exception as e:
            self.get_logger().error(f'Error al convertir: {e}')
            return

        hsv = cv2.cvtColor(cv_image, cv2.COLOR_BGR2HSV)

        red_h_low1 = self.get_parameter('red_h_low1').value
        red_h_high1 = self.get_parameter('red_h_high1').value
        red_s_low1 = self.get_parameter('red_s_low1').value
        red_s_high1 = self.get_parameter('red_s_high1').value
        red_v_low1 = self.get_parameter('red_v_low1').value
        red_v_high1 = self.get_parameter('red_v_high1').value

        red_h_low2 = self.get_parameter('red_h_low2').value
        red_h_high2 = self.get_parameter('red_h_high2').value
        red_s_low2 = self.get_parameter('red_s_low2').value
        red_s_high2 = self.get_parameter('red_s_high2').value
        red_v_low2 = self.get_parameter('red_v_low2').value
        red_v_high2 = self.get_parameter('red_v_high2').value

        green_h_low = self.get_parameter('green_h_low').value
        green_h_high = self.get_parameter('green_h_high').value
        green_s_low = self.get_parameter('green_s_low').value
        green_s_high = self.get_parameter('green_s_high').value
        green_v_low = self.get_parameter('green_v_low').value
        green_v_high = self.get_parameter('green_v_high').value

        red_lower1 = np.array([red_h_low1, red_s_low1, red_v_low1])
        red_upper1 = np.array([red_h_high1, red_s_high1, red_v_high1])
        red_lower2 = np.array([red_h_low2, red_s_low2, red_v_low2])
        red_upper2 = np.array([red_h_high2, red_s_high2, red_v_high2])
        green_lower = np.array([green_h_low, green_s_low, green_v_low])
        green_upper = np.array([green_h_high, green_s_high, green_v_high])

        mask_red1 = cv2.inRange(hsv, red_lower1, red_upper1)
        mask_red2 = cv2.inRange(hsv, red_lower2, red_upper2)
        mask_red = cv2.bitwise_or(mask_red1, mask_red2)
        mask_green = cv2.inRange(hsv, green_lower, green_upper)

        contornos_rojo = self.filtrar_por_forma(mask_red)
        contornos_verde = self.filtrar_por_forma(mask_green)

        red_pixels = sum(cv2.contourArea(c) for c in contornos_rojo)
        green_pixels = sum(cv2.contourArea(c) for c in contornos_verde)

        if red_pixels > 500 and green_pixels <= 500:
            self.ultimo_color = 'red'
            self.get_logger().info('🔴 ROJO válido → 20 cm')
        elif green_pixels > 500 and red_pixels <= 500:
            self.ultimo_color = 'green'
            self.get_logger().info('🟢 VERDE válido → 60 cm')
        else:
            if self.ultimo_color is not None:
                self.get_logger().info(f'⚪ Sin forma válida → manteniendo {self.ultimo_color.upper()}')

    # ============================================================
    # FUNCIONES DE NAVEGACIÓN (LIDAR + PID)
    # ============================================================
    def distancia_moda(self, distancias, bin_width=0.02):
        if not distancias:
            return 999.0
        min_d = min(distancias)
        max_d = max(distancias)
        if max_d - min_d < bin_width:
            return np.mean(distancias)
        bins = np.arange(min_d, max_d + bin_width, bin_width)
        digitized = np.digitize(distancias, bins)
        counts = Counter(digitized)
        moda_bin_idx = max(counts, key=counts.get)
        centro_bin = (bins[moda_bin_idx - 1] + bins[moda_bin_idx]) / 2 if moda_bin_idx > 0 else bins[0]
        return centro_bin

    def detectardistancias(self, msg):
        dist_f, dist_d, dist_i = [], [], []
        for i, rango in enumerate(msg.ranges):
            if msg.range_min < rango < msg.range_max:
                angulo = np.degrees(msg.angle_min + (i * msg.angle_increment)) % 360
                if 75 <= angulo <= 105:
                    dist_f.append(rango)
                elif 165 <= angulo <= 195:
                    dist_d.append(rango)
                elif angulo >= 345 or angulo <= 15:
                    dist_i.append(rango)
        self.d = self.distancia_moda(dist_f)
        self.dd = self.distancia_moda(dist_d)
        self.di = self.distancia_moda(dist_i)

    def obtener_puntos_sector(self, msg, ang_min, ang_max):
        distancias_raw, angulos_raw = [], []
        for i, rango in enumerate(msg.ranges):
            if msg.range_min < rango < msg.range_max:
                angulo_rad = msg.angle_min + (i * msg.angle_increment)
                angulo_deg = np.degrees(angulo_rad) % 360
                en_rango = (ang_min <= angulo_deg <= ang_max) if ang_min < ang_max else (angulo_deg >= ang_min or angulo_deg <= ang_max)
                if en_rango:
                    distancias_raw.append(rango)
                    angulos_raw.append(angulo_rad)
        if not distancias_raw:
            return [], []
        moda = self.distancia_moda(distancias_raw)
        if moda == 999.0:
            return [], []
        umbral = max(0.1, 0.2 * moda)
        distancias_filtradas, angulos_filtrados = [], []
        for r, a in zip(distancias_raw, angulos_raw):
            if abs(r - moda) <= umbral:
                distancias_filtradas.append(r)
                angulos_filtrados.append(a)
        return distancias_filtradas, angulos_filtrados

    def calcular_pid_svd(self, distancias, angulos, dist_obj, limite_ang, dt, es_derecha):
        Kp_d = self.get_parameter('Kp_dist').value
        Kd_d = self.get_parameter('Kd_dist').value
        Ki_d = self.get_parameter('Ki_dist').value
        Kp_a = self.get_parameter('Kp_ang').value
        Kd_a = self.get_parameter('Kd_ang').value

        X = np.array([r * np.cos(a) for r, a in zip(distancias, angulos)])
        Y = np.array([r * np.sin(a) for r, a in zip(distancias, angulos)])

        X_mean, Y_mean = np.mean(X), np.mean(Y)
        X_c, Y_c = X - X_mean, Y - Y_mean
        _, _, Vh = np.linalg.svd(np.vstack([X_c, Y_c]).T)
        dir_x, dir_y = Vh[0]
        norm_x, norm_y = Vh[1]

        if dir_y < 0:
            dir_x, dir_y = -dir_x, -dir_y

        angulo_vector = np.degrees(np.arctan2(dir_y, dir_x))

        if es_derecha:
            error_angulo_real = 90.0 - angulo_vector
        else:
            error_angulo_real = angulo_vector - 90.0
            error_angulo_real = (error_angulo_real + 180) % 360 - 180

        distancia_pared = abs(X_mean * norm_x + Y_mean * norm_y)
        error_distancia = dist_obj - distancia_pared

        derivada_dist = (error_distancia - self.prev_error_dist) / dt
        self.integral_dist = max(-0.5, min(0.5, self.integral_dist + (error_distancia * dt)))
        salida_distancia = (Kp_d * error_distancia) + (Kd_d * derivada_dist) + (Ki_d * self.integral_dist)

        derivada_ang = (error_angulo_real - self.prev_error_ang) / dt
        salida_angulo = (Kp_a * error_angulo_real) + (Kd_a * derivada_ang)

        self.prev_error_dist = error_distancia
        self.prev_error_ang = error_angulo_real

        correccion_total = int(salida_distancia + salida_angulo)

        if error_angulo_real >= limite_ang and correccion_total < 0:
            correccion_total = 0
        elif error_angulo_real <= -limite_ang and correccion_total > 0:
            correccion_total = 0

        return correccion_total, distancia_pared, error_angulo_real

    # ============================================================
    # FUNCIONES DE SEGUIMIENTO DE PARED (con velocidad y distancia personalizables)
    # ============================================================
    def detectarderecha_con_velocidad(self, msg, dt, vel, dist_obj):
        limite_ang = float(self.get_parameter('limite_angulo_max').value)
        distancias, angulos = self.obtener_puntos_sector(msg, 165, 195)
        if len(distancias) < 5:
            self.enviar_a_arduino(velocidad=vel, angulo_servo=self.rec)
            return
        correccion, dist_pared, err_ang = self.calcular_pid_svd(
            distancias, angulos, dist_obj, limite_ang, dt, es_derecha=True
        )
        self.error_angulo_actual = err_ang
        angulo_servo = self.rec - correccion
        angulo_servo = max(self.izquierda, min(self.derecha, angulo_servo))
        self.enviar_a_arduino(velocidad=vel, angulo_servo=angulo_servo)

    def detectarizquierda_con_velocidad(self, msg, dt, vel, dist_obj):
        limite_ang = float(self.get_parameter('limite_angulo_max').value)
        distancias, angulos = self.obtener_puntos_sector(msg, 345, 15)
        if len(distancias) < 5:
            self.enviar_a_arduino(velocidad=vel, angulo_servo=self.rec)
            return
        correccion, dist_pared, err_ang = self.calcular_pid_svd(
            distancias, angulos, dist_obj, limite_ang, dt, es_derecha=False
        )
        self.error_angulo_actual = err_ang
        angulo_servo = self.rec + correccion
        angulo_servo = max(self.izquierda, min(self.derecha, angulo_servo))
        self.enviar_a_arduino(velocidad=vel, angulo_servo=angulo_servo)

    def detectarderecha(self, msg, dt, vel, dist_obj):
        limite_ang = float(self.get_parameter('limite_angulo_max').value)
        distancias, angulos = self.obtener_puntos_sector(msg, 165, 195)
        if len(distancias) < 5:
            self.enviar_a_arduino(velocidad=vel, angulo_servo=self.rec)
            return
        correccion, dist_pared, err_ang = self.calcular_pid_svd(
            distancias, angulos, dist_obj, limite_ang, dt, es_derecha=True
        )
        self.error_angulo_actual = err_ang
        angulo_servo = self.rec - correccion
        angulo_servo = max(self.izquierda, min(self.derecha, angulo_servo))
        self.enviar_a_arduino(velocidad=vel, angulo_servo=angulo_servo)

    def detectarizquierda(self, msg, dt, vel, dist_obj):
        limite_ang = float(self.get_parameter('limite_angulo_max').value)
        distancias, angulos = self.obtener_puntos_sector(msg, 345, 15)
        if len(distancias) < 5:
            self.enviar_a_arduino(velocidad=vel, angulo_servo=self.rec)
            return
        correccion, dist_pared, err_ang = self.calcular_pid_svd(
            distancias, angulos, dist_obj, limite_ang, dt, es_derecha=False
        )
        self.error_angulo_actual = err_ang
        angulo_servo = self.rec + correccion
        angulo_servo = max(self.izquierda, min(self.derecha, angulo_servo))
        self.enviar_a_arduino(velocidad=vel, angulo_servo=angulo_servo)

    # ============================================================
    # ENVIAR COMANDOS AL ARDUINO
    # ============================================================
    def enviar_a_arduino(self, velocidad, angulo_servo):
        if self.arduino and self.arduino.is_open:
            try:
                self.arduino.write(f"M{velocidad}\n".encode('utf-8'))
                self.arduino.write(f"S{angulo_servo}\n".encode('utf-8'))
                self.velocidad_actual = velocidad
            except Exception as e:
                self.get_logger().error(f'Error de transmisión serial: {e}')

    # ============================================================
    # GIROS Y SENTIDO
    # ============================================================
    def giroizq90(self, vel):
        self.enviar_a_arduino(velocidad=vel, angulo_servo=self.izquierda)

    def giroder90(self, vel):
        self.enviar_a_arduino(velocidad=vel, angulo_servo=self.derecha)

    def detectarlado_en_pared(self):
        if self.dd < self.di:
            self.sentido = 2
        else:
            self.sentido = 1

    # ============================================================
    # MANIOBRA DE CRUCE
    # ============================================================
    def iniciar_cruce(self, vel):
        self.cruce_activo = True
        self.cruce_fase = 1
        self.cruce_tiempo_inicio = time.time()
        self.cruce_vel = vel
        self.get_logger().warn('🚦 INICIANDO MANIOBRA DE CRUCE')
        self.get_logger().info('⬅️ Fase 1: Retrocediendo 2 segundos...')
        self.enviar_a_arduino(velocidad=-100, angulo_servo=self.rec)

    def procesar_cruce(self):
        if not self.cruce_activo:
            return

        tiempo_actual = time.time()
        tiempo_transcurrido = tiempo_actual - self.cruce_tiempo_inicio

        if self.cruce_fase == 1:
            if tiempo_transcurrido >= 2.0:
                self.cruce_fase = 2
                self.cruce_tiempo_inicio = tiempo_actual
                self.get_logger().info('🔄 Fase 2: Girando 90°...')
                if self.sentido == 1:
                    self.enviar_a_arduino(velocidad=self.cruce_vel, angulo_servo=self.izquierda)
                else:
                    self.enviar_a_arduino(velocidad=self.cruce_vel, angulo_servo=self.derecha)

        elif self.cruce_fase == 2:
            if tiempo_transcurrido >= self.TIEMPO_GIRO:
                self.cruce_fase = 3
                self.cruce_tiempo_inicio = tiempo_actual
                self.get_logger().info('📏 Fase 3: Retrocediendo con PID (5cm de pared)...')

        elif self.cruce_fase == 3:
            if self.last_scan_msg is None:
                return

            dt = 0.1
            if self.sentido == 1:
                self.detectarizquierda_con_velocidad(self.last_scan_msg, dt, -100, self.cruce_distancia_objetivo)
            else:
                self.detectarderecha_con_velocidad(self.last_scan_msg, dt, -100, self.cruce_distancia_objetivo)

            if int(tiempo_transcurrido) % 1 == 0 and tiempo_transcurrido > 0:
                self.get_logger().info(f'📏 Retrocediendo... ({tiempo_transcurrido:.1f}s)')

            if tiempo_transcurrido >= 5.0 or abs(self.error_angulo_actual) < 2.0:
                self.cruce_fase = 4
                self.cruce_tiempo_inicio = tiempo_actual
                self.get_logger().info('✅ Fase 4: Avanzando y reanudando...')
                self.enviar_a_arduino(velocidad=self.cruce_vel, angulo_servo=self.rec)

        elif self.cruce_fase == 4:
            if tiempo_transcurrido >= 1.0:
                self.cruce_activo = False
                self.cruce_fase = 0
                self.girando = False
                self.giros_completados += 1
                self.reiniciar_memoria_color()
                self.get_logger().info('✅ Maniobra de cruce COMPLETADA')

    # ============================================================
    # LIDAR CALLBACK
    # ============================================================
    def lidar_callback(self, msg):
        current_time = self.get_clock().now()
        dt = (current_time - self.last_time).nanoseconds / 1e9
        self.last_time = current_time

        if dt <= 0:
            return

        self.last_scan_msg = msg
        self.detectardistancias(msg)

        if self.cruce_activo:
            self.procesar_cruce()
            return
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

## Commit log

2026-08-19 se agrego una base del github usado en la competencia pasadas
    apartir de aca se realizaron todos los cambios que fueron realizados al robot actualmente
2026-08-19 Se agrego la explicacion electronica
    Se agrego el readme para implementar toda la parte electronica y el porque de cada decision.
2026-08-21 Se agrego toda la informacion relacionado a los componentes electronicos
    Se agrego toda la informacion de la electronica, ademas de la distribucion, tiempo de autonomia e informacion de cada uno de los componentes
2026-08-21 Se borro toda la informacion irrelevante y desactualizada
    Debido a que se utilizo una version antigua del repositorio, se elimino toda aquella informacion que no informaba sobre el robot actual
2026-08-21 Se agregaron mas datos sobre la construccion
    En la parte electronica, se agrego toda la informacion sobre la construccion, y la explicacion de porque cada uno de los componentes es utilizado
2026-08-21 Se agrego toda la explicacion del codigo
    Se explica detalladamente como descargar, utilizar y los archivos necesarios para replicar el movimiento de nuestro robot.
2026-08-21 Se arreglaron errores de formato
2026-08-22 Se agregaron las foto de los componentes
    se agregaron las fotos de todos los componentes y se arreglo la version de ubuntu recomendada y por lo tanto la version de ros2 de humble a jazzy
2026-08-23 Se agrego un diagrama de flujo
    Se agrego el diagrama de flujo del reto 1 y se agregaron notas a la parte del codigo
2026-08-23 Actualización del Readme
    se actualiza informacion del equipo, objetivos del repositorio y parte de la historia de redmachine, junto a la razon de diversos cambios que se han realizado en el robot (estructuras y componentes)
2026-08-23 Se agrego informacion de la electronica
2026-08-24 se agrego un diagrama de ejemplo
2026-09-04 Se agregaron las decisiones de ingenieria al final del github
2026-09-09 se actualizo el indice
2026-09-11 se añaden modelos
    se añade la carpeta models donde se pueden descargar los modelos 3D del chasis de pompo, y se añade una foto en la carpeta v-photos
    [2DO P.stl, AGAIN 1.stl, CONECTOR MOTOR-EJE.stl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]
2026-09-12 se añade video de reto 2
    se añade el link directo para acceder al video de Youtube del segundo reto realizado por pompo, asi como el link que facilita el acceso rapido a dicho video
2026-09-15 actualizacion
    se añaden mas decisiones de ingenieria por las que el equipo a pasado a lo largo de sus años de competencia, tanto en diseño, programacion, alimentancion y demas areas
2026-09-15 actualizacion
    se añade un resumen del diseño evolutivo del robot en el que se puede apreciar facilmente los diversos cambios por lo que ha pasado y como han evolucionado los prototipos
